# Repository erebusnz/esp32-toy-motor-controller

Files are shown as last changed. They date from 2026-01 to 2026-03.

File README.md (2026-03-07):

# ESP32 Toy Motor Controller

A compact dual DC motor controller board designed around the **ESP32S3-Super Mini** module and the **TB6612FNG** dual H-bridge motor driver.

This project targets small toy hacking with reliable bidirectional DC motor control, PWM speed control, and simple GPIO-controlled switching of accessories.

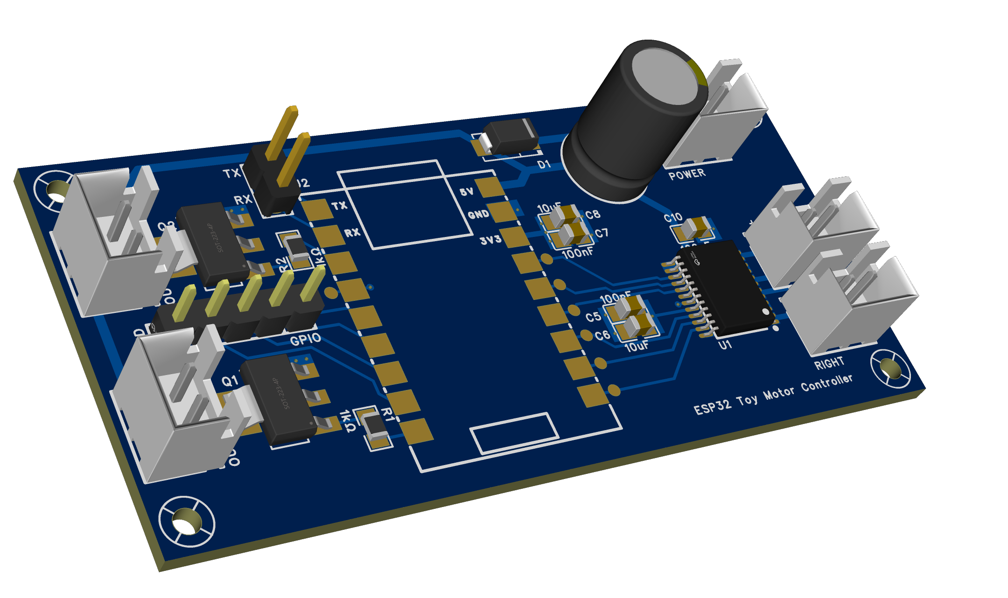
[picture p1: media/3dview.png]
3D PCB Render


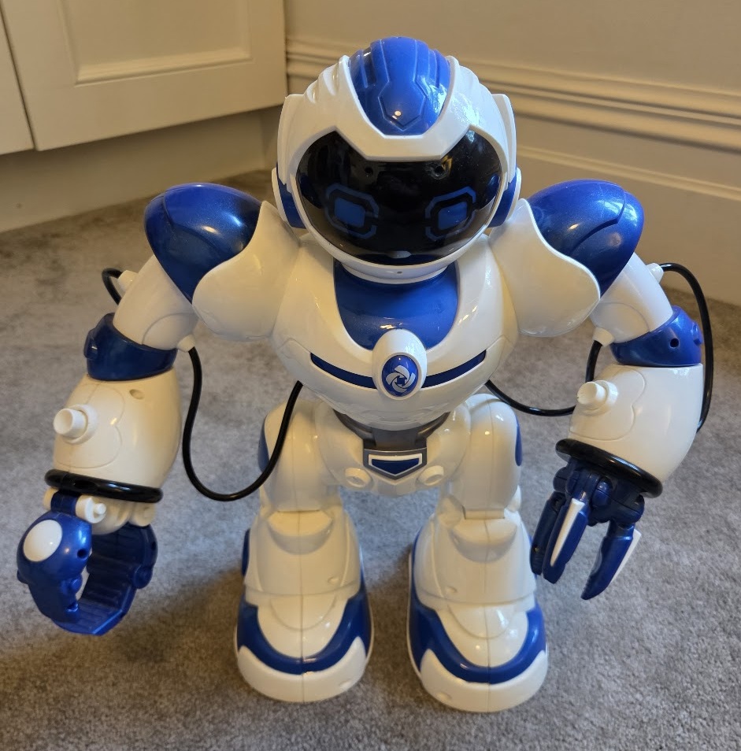
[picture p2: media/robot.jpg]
Robot
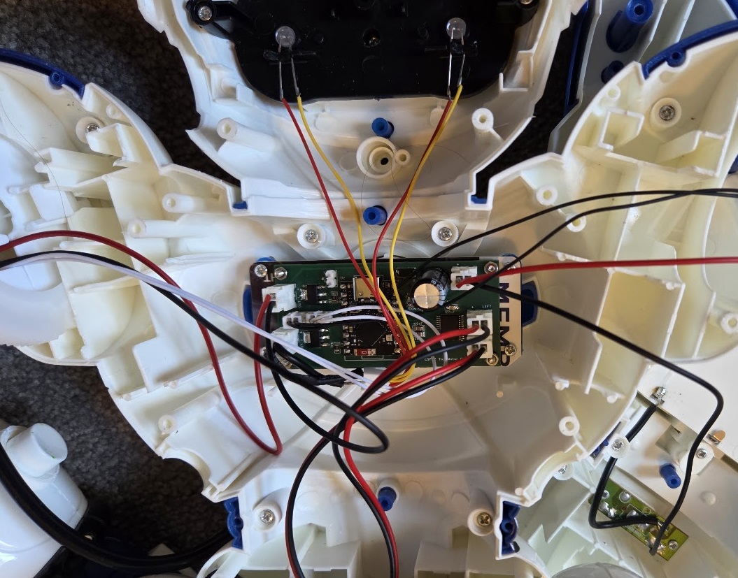
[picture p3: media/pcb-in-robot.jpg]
PCB installed in robot
|  |  |
|:---:|:---:|
| Target toy | PCB installed inside |

---

## Overview

The board integrates:
- An **ESP32S3-Super Mini** module
- A **TB6612FNG** dual H-bridge motor driver
- Two GPIO-controlled low-side switches using NPN transistors
- On-board decoupling and bulk capacitance for motor stability
- Schottky diode reverse polarity protection on the motor supply input
- Serial header and expansion GPIO header

---

## Key Features

- Dual DC motor control (independent speed and direction)
- ESP32-S3 controller with Wi-Fi / BLE capability
- Efficient TB6612FNG motor driver (lower loss than legacy H-bridges)
- Two low-side switched outputs using NPN transistors

---

## Hardware Architecture

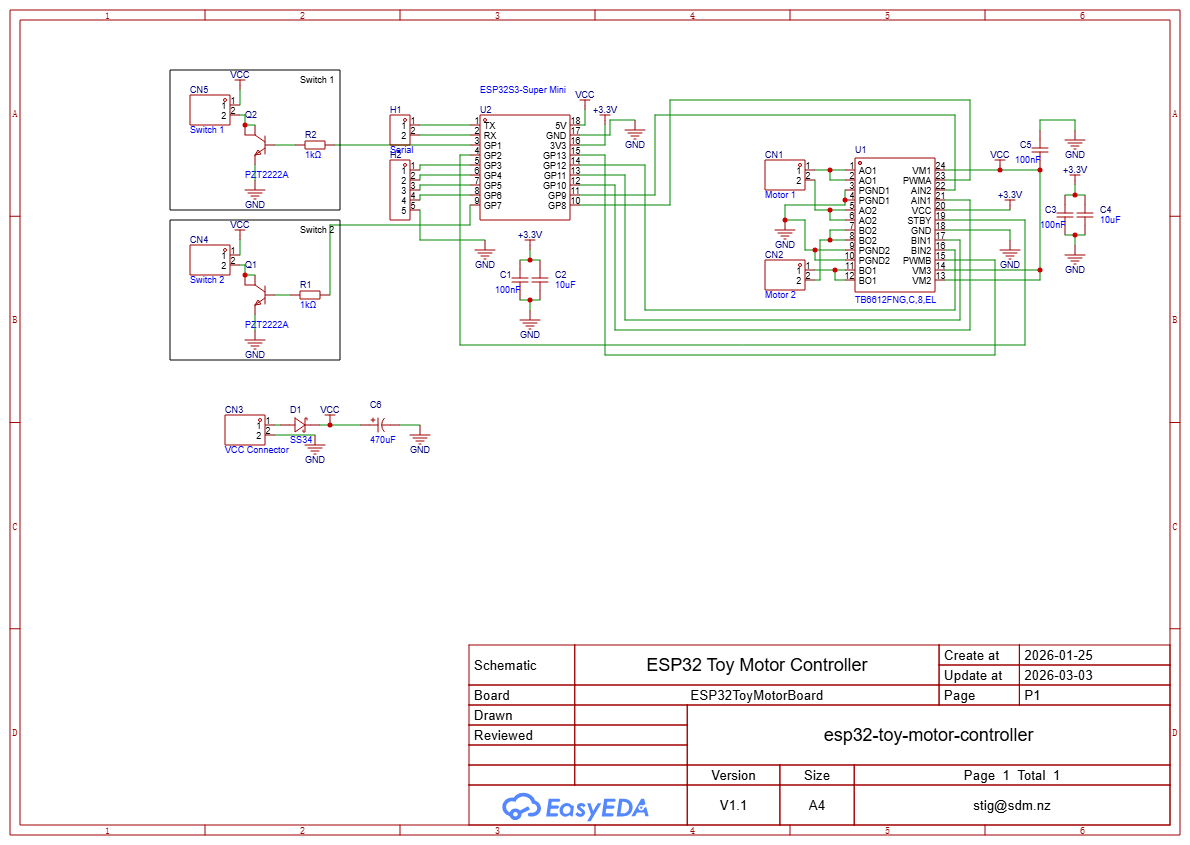
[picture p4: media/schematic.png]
Schematic


### Microcontroller

- **ESP32S3-Super Mini**
- GPIOs directly control motor driver and switch circuitry

### Motor Driver

- **TB6612FNG Dual H-Bridge**
- Motor connections:
  - Motor A: AO1 / AO2
  - Motor B: BO1 / BO2
- Control signals:
  - AIN1, AIN2, PWMA
  - BIN1, BIN2, PWMB
- Motor supply via VM (VCC)

### Power

- **VCC input connector (CN3)**
  - Supplies motor driver VM
  - SS34 Schottky diode (D1) provides reverse polarity protection (~0.4 V forward drop)
  - Bulk capacitor: 470 µF for transient suppression
- **3.3 V logic rail**
  - Local decoupling: 100 nF + 10 µF
- Common ground between logic and motor domains

### Switch Outputs (Low-Side Switching)

- Two GPIO-controlled switches implemented using **NPN transistors**
- Low-side switching topology
- Suitable for driving small loads referenced to VCC

---

## Connectors

| Connector | Function |
|---|---|
| CN1 | Motor 1 output (RIGHT) |
| CN2 | Motor 2 output (LEFT) |
| CN3 | VCC power input |
| CN4 | Switch 2 output |
| CN5 | Switch 1 output |
| H1 | Serial header (TX, RX) |
| H2 | GPIO expansion header (GP3–GP6, GND) |

---

## ESP32S3-Super Mini GPIO Mapping

### Motor Driver (TB6612FNG)

| ESP32S3-Super Mini GPIO | TB6612FNG Signal | Function |
|---|---|---|
| GP2  | STBY | Motor driver enable (HIGH = enabled) |
| GP8  | PWMA | Motor A speed |
| GP10 | AIN1 | Motor A direction |
| GP9  | AIN2 | Motor A direction |
| GP13 | PWMB | Motor B speed |
| GP11 | BIN1 | Motor B direction |
| GP12 | BIN2 | Motor B direction |

### Switch Control

| ESP32S3-Super Mini GPIO | Function |
|---|---|
| GP1 | Switch 1 control |
| GP7 | Switch 2 control |

- Switches use **NPN low-side switching** (PZT2222A): drive GPIO **HIGH to turn the switch ON**, **LOW to turn it OFF**.
- Both switches default to OFF (GPIO LOW) at boot.

### GPIO Expansion (H2)

| H2 Pin | ESP32S3-Super Mini GPIO |
|---|---|
| 1 | GP3 |
| 2 | GP4 |
| 3 | GP5 |
| 4 | GP6 |
| 5 | GND |

---

## Arduino Sketches

### Arduino IDE Setup

- **Board:** ESP32S3 Dev Module
- **Core:** Espressif ESP32 Arduino core v3.x or later — required for `ledcAttach()`. Install via Arduino IDE > Boards Manager > "esp32 by Espressif Systems" >= 3.0.0
- **USB CDC On Boot:** Enabled (for Serial monitor over USB)

All sketches that require WiFi credentials use a `secrets.h` file (not committed). Copy `example.secrets.h` (or `secrets.h.example`) to `secrets.h` and fill in your details:

```cpp
const char *ssid     = "your-network-name";
const char *password = "your-password";
```

---

### `motor-switch-test` — Hardware Test

[`arduino/motor-switch-test/`](arduino/motor-switch-test/)

Confirms motors, switches, and GPIO wiring are working correctly. No WiFi required.

**What it does:**
1. Runs both motors **forward** for 2 s (LED on, SW1 on, SW2 off)
2. Coasts briefly (400 ms)
3. Runs both motors **backward** for 2 s (LED off, SW1 off, SW2 on)
4. Coasts and repeats

**Serial output (115200 baud):**
```
Motor controller ready.
Motor A + B: FORWARD  | SW1 ON, SW2 OFF
Motor A + B: BACKWARD | SW1 OFF, SW2 ON
...
```

---

### `example-ota-controller` — Hardware Test with OTA

[`arduino/example-ota-controller/`](arduino/example-ota-controller/)

Same forward/backward loop as `motor-switch-test`, but adds WiFi connectivity and **ArduinoOTA** support so subsequent firmware updates can be pushed wirelessly.

**After the initial USB flash:**
```bash
python "espota.py" \
  -i <device-ip> \
  -f "build/esp32.esp32.esp32s3/example-ota-controller.ino.bin"
```

The device IP is printed over serial on boot.

Requires `secrets.h` with WiFi credentials (see above).

---

### `wifi-browser-control` — Browser-Based Remote Control

[`arduino/wifi-browser-control/`](arduino/wifi-browser-control/)

Full differential-drive controller served from the ESP32 as a mobile-friendly web page. Includes ArduinoOTA.

Open `http://<device-ip>` in any browser:

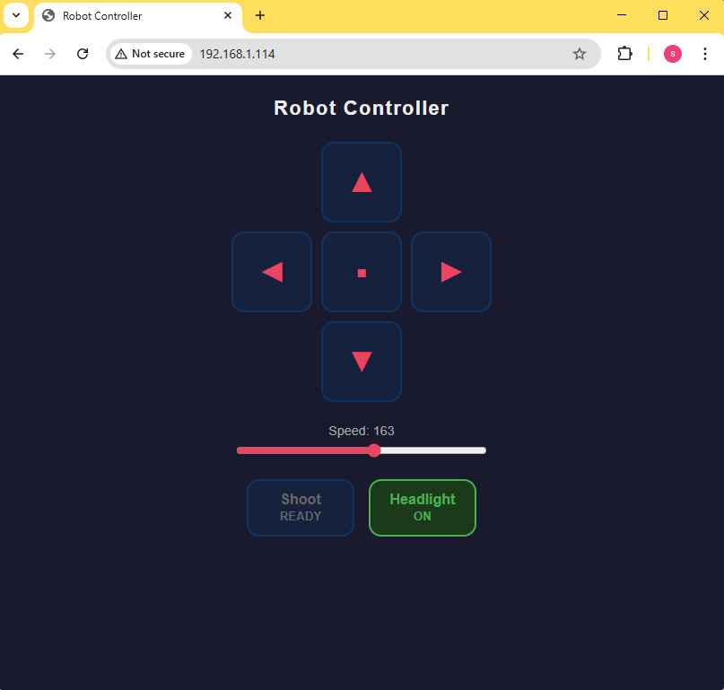
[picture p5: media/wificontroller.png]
Browser controller interface


| Control | Behaviour |
|---|---|
| **↑ Forward** | Both motors forward — hold to move |
| **↓ Backward** | Both motors backward — hold to move |
| **← Left** | Pivot left (right motor fwd, left motor bwd) — hold |
| **→ Right** | Pivot right (left motor fwd, right motor bwd) — hold |
| **■ Stop** | Immediately stops both motors |
| **Speed slider** | Sets motor PWM duty cycle (50–255) |
| **Shoot** | Triggers SW1 for 5 seconds then auto-stops |
| **Headlight** | Toggles SW2 on/off |

Direction buttons stop motors on release. Re-pressing Shoot resets the 5-second timer.

If a motor runs in the wrong direction, flip its flag in the sketch instead of swapping wires:
```cpp
#define REVERSE_RIGHT  true   // CN1 — set true if right motor runs backward
#define REVERSE_LEFT   false  // CN2 — set true if left motor runs backward
```

**OTA upload after initial flash:**
```bash
python "espota.py" \
  -i <device-ip> \
  -f "build/esp32.esp32.esp32s3/wifi-browser-control.ino.bin"
```

Requires `secrets.h` with WiFi credentials (see above).

---

## Power & Electrical Considerations

- Design is intended for **small DC motors and low-current switched loads**
- Motor supply reverse polarity protected by SS34 Schottky diode (~0.4 V drop)
- **Use a dedicated 5 V 1 A+ supply** — USB power causes the 3.3 V rail to sag
- No current sensing
- External motor suppression may be required for noisy loads

---

## Notes & Limitations

- Not suitable for high-current motors
- No hardware fault protection
- ESP32 module pinout must match the 18-pin layout described above

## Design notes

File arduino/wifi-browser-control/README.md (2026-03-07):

# WiFi Browser Control

Browser-based controller for the ESP32S3 toy motor controller PCB.
Drives two DC motors (differential drive) and controls a shoot actuator and headlight via a mobile-friendly webpage.

## Hardware

- **MCU:** ESP32S3-Super Mini
- **Motor driver:** TB6612FNG dual H-bridge
- **Supply:** 5 V, 1 A minimum (USB power causes 3.3 V rail sag — use a dedicated supply)

## PCB Connectors

| Connector | Silkscreen label | Function | GPIO | Notes |
|---|---|---|---|---|
| **CN1** | Right | Right motor | — | |
| **CN2** | Left | Left motor | — | |
| **CN4** | Out 2 | Headlight | GP7  | Requires current-limiting resistor — 68 Ω for LED |
| **CN5** | Out 1 | Shoot actuator | GP1  | |

> If a motor runs in the wrong direction, flip its flag in the sketch instead of swapping wires:
> ```cpp
> #define REVERSE_RIGHT  true   // CN1 — set true if right motor runs backward
> #define REVERSE_LEFT   false  // CN2 — set true if left motor runs backward
> ```

## GPIO Map

| GPIO | Function |
|---|---|
| 2 | STBY (motor enable) |
| 8 | PWMA (right motor speed) |
| 9 | AIN2 |
| 10 | AIN1 |
| 11 | BIN1 |
| 12 | BIN2 |
| 13 | PWMB (left motor speed) |
| 1 | SW1 — Shoot actuator (CN5) |
| 7 | SW2 — Headlight (CN4) |
| 48 | Onboard LED |

## Arduino IDE Setup

| Setting | Value |
|---|---|
| Board | ESP32S3 Dev Module |
| Core | Espressif ESP32 v3.x or later |
| USB CDC On Boot  | Enabled |
| Upload speed | 921600 |

WiFi credentials go in `secrets.h` (not committed). Rename `example.secrets.h` to `secrets.h` and fill in your details:

```cpp
const char *ssid     = "your-network-name";
const char *password = "your-password";
```

## OTA Upload
After the initial USB flash, subsequent uploads can remote upload firmware over wifi using `espota.py`:

In Arduino 2 use Sketch -> Export Compiled Binary then:

```bash
python "espota.py" \
  -i <device-ip> \
  -f "build/esp32.esp32.esp32s3/wifi-browser-control.ino.bin"
```

The device IP is printed over serial on boot.

## Web Interface

Open `http://<device-ip>` in any browser (works on mobile).

Browser controller interface

| Control | Behaviour |
|---|---|
| **↑ Forward** | Both motors forward — hold to move |
| **↓ Backward**  | Both motors backward — hold to move |
| **← Left** | Pivot left (right motor fwd, left motor bwd) — hold |
| **→ Right** | Pivot right (left motor fwd, right motor bwd) — hold |
| **■ Stop** | Immediately stops both motors |
| **Speed slider**| Sets motor PWM duty cycle (50–255) |
| **Shoot** | Triggers SW1 actuator for 5 seconds then auto-stops |
| **Headlight** | Toggles SW2 on/off |

Direction buttons stop the motors on release. The Shoot button re-pressing resets the 5-second timer.

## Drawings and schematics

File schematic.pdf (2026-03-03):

# GP8 10 GP9 11 GP10 12 GP11 13 GP12 14 GP13 15 3V3 16 GND 17 5V 18

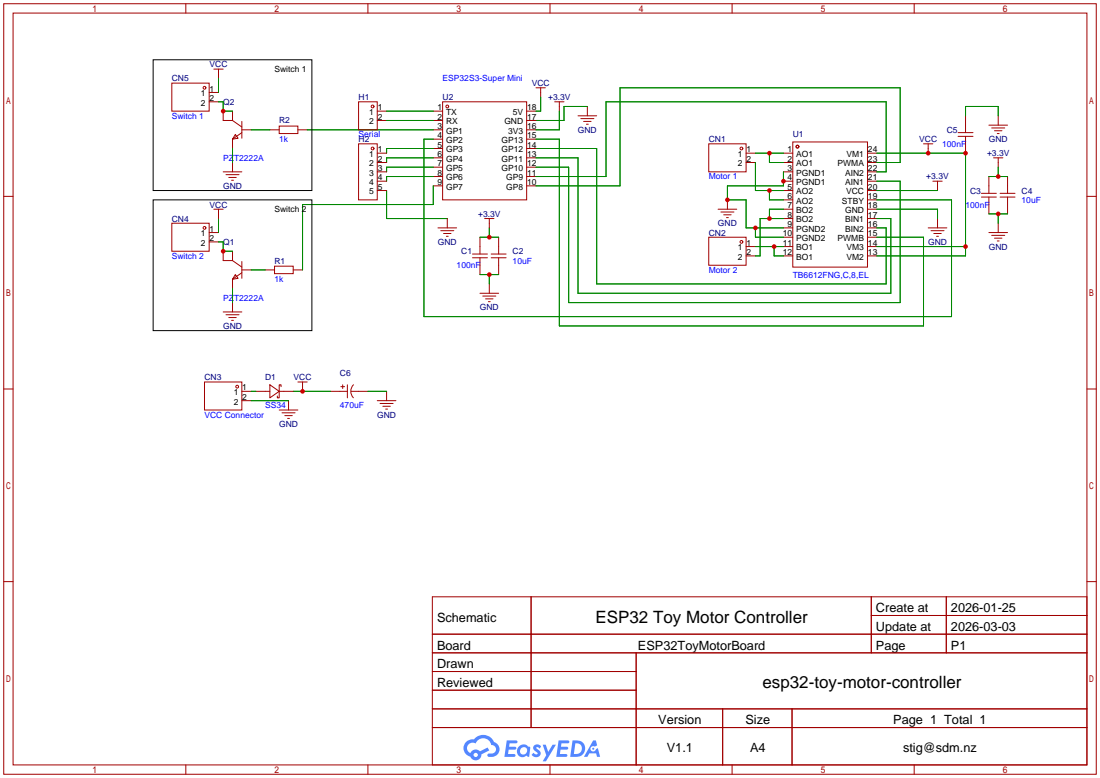
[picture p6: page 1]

Schematic | ESP32 Toy Motor Controller | Create at | 2026-01-25

Update at | 2026-03-03

Board | ESP32ToyMotorBoard | Page | P1
Drawn | | esp32-toy-motor-controller
Reviewed

Version | Size | Page 1 Total 1
V1.1 | A4 | stig@sdm.nz

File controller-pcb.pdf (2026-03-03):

# ESP32 Toy Motor Controller +

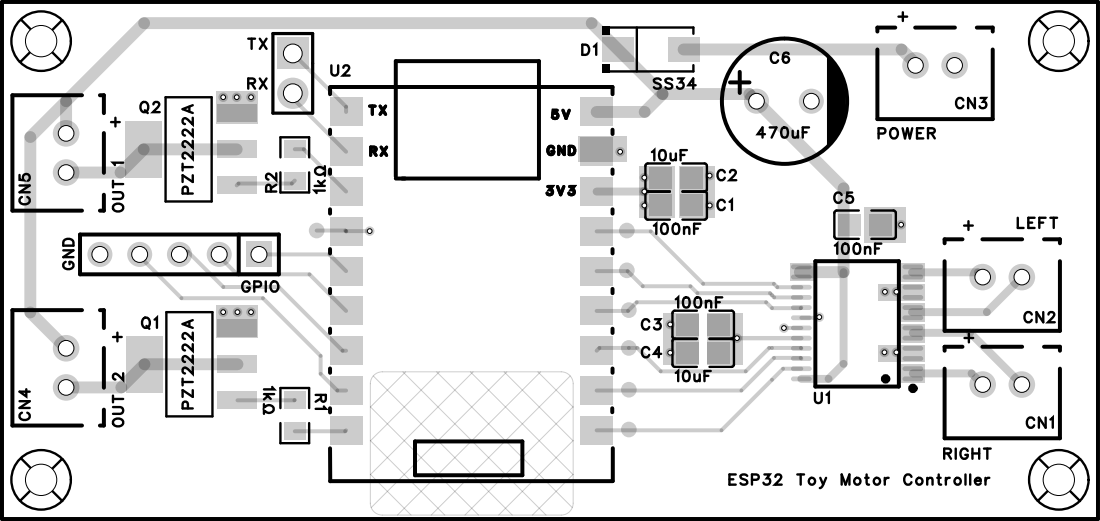
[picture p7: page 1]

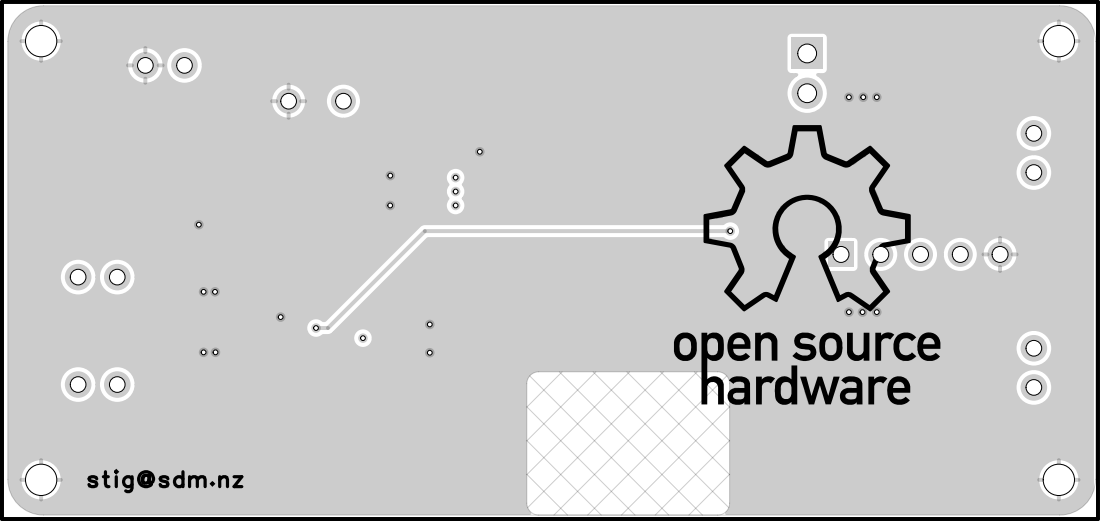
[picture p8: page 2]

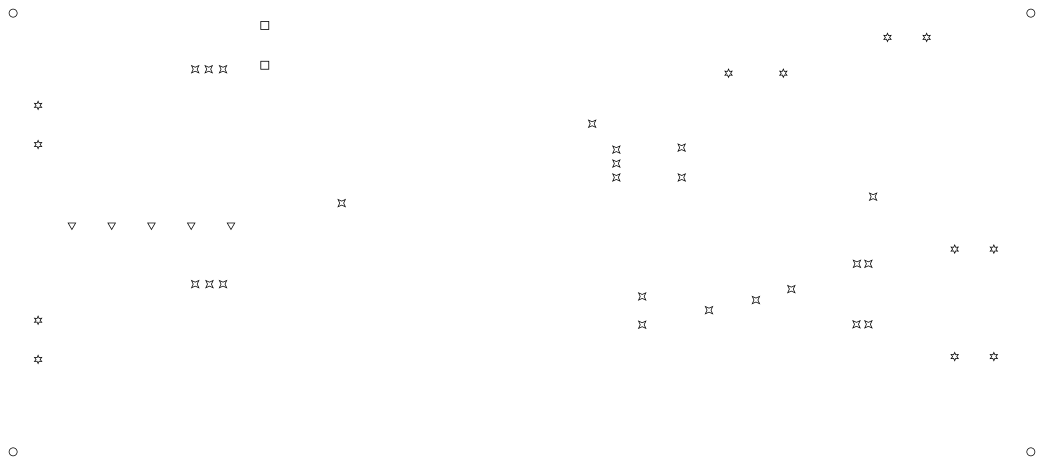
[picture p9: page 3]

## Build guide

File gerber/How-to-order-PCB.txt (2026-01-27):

How to Order PCB

Please refer to:
https://prodocs.easyeda.com/en/pcb/order-order-pcb/index.html

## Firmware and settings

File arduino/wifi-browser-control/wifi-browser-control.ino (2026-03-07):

// ESP32 Toy Motor Controller - WiFi Browser Control with OTA
// Hardware: ESP32S3-Super Mini + TB6612FNG dual H-bridge motor driver
//
// IMPORTANT - Arduino IDE setup:
//   Board:     ESP32S3 Dev Module
//   Core:      Espressif ESP32 Arduino core v3.x or later (required for ledcAttach)
//   Upload speed: 921600, USB CDC On Boot: Enabled

#include <WiFi.h>
#include "esp_wifi.h"
#include <ESPmDNS.h>
#include <NetworkUdp.h>
#include <ArduinoOTA.h>
#include <WebServer.h>
#include "secrets.h"

uint32_t last_ota_time = 0;

// --- Motor A Pins (TB6612FNG) - Left motor ---
#define PWMA  8
#define AIN1  10
#define AIN2  9

// --- Motor B Pins (TB6612FNG) - Right motor ---
#define PWMB  13
#define BIN1  11
#define BIN2  12

// --- TB6612FNG Standby (HIGH = enabled, LOW = standby) ---
#define STBY  2

// --- Switch Outputs (NPN low-side: HIGH = ON, LOW = OFF) ---
#define SW1   1
#define SW2   7

// --- Onboard LED ---
#define LED   48

// --- Motor direction flags ---
// Set to true if a motor runs backward — avoids swapping physical wires
#define REVERSE_RIGHT  true   // CN1 Right motor
#define REVERSE_LEFT   false  // CN2 Left motor

// --- PWM Settings ---
#define PWM_FREQ        5000
#define PWM_RESOLUTION  8     // 0-255

// TB6612FNG direction truth table:
//   AIN1=H, AIN2=L -> Forward
//   AIN1=L, AIN2=H -> Backward
//   AIN1=L, AIN2=L -> Coast (stop)

bool sw1_state = false;
bool sw2_state = false;
uint32_t sw1_off_at = 0;  // millis() timestamp to auto-off SW1 (0 = not scheduled)

WebServer server(80);

// ----- Motor helpers -----

void motorA_forward(uint8_t speed) {
  digitalWrite(AIN1, REVERSE_RIGHT ? LOW  : HIGH);
  digitalWrite(AIN2, REVERSE_RIGHT ? HIGH : LOW);
  ledcWrite(PWMA, speed);
}
void motorA_backward(uint8_t speed) {
  digitalWrite(AIN1, REVERSE_RIGHT ? HIGH : LOW);
  digitalWrite(AIN2, REVERSE_RIGHT ? LOW  : HIGH);
  ledcWrite(PWMA, speed);
}
void motorA_stop() {
  digitalWrite(AIN1, LOW); digitalWrite(AIN2, LOW);
  ledcWrite(PWMA, 0);
}

void motorB_forward(uint8_t speed) {
  digitalWrite(BIN1, REVERSE_LEFT ? LOW  : HIGH);
  digitalWrite(BIN2, REVERSE_LEFT ? HIGH : LOW);
  ledcWrite(PWMB, speed);
}
void motorB_backward(uint8_t speed) {
  digitalWrite(BIN1, REVERSE_LEFT ? HIGH : LOW);
  digitalWrite(BIN2, REVERSE_LEFT ? LOW  : HIGH);
  ledcWrite(PWMB, speed);
}
void motorB_stop() {
  digitalWrite(BIN1, LOW); digitalWrite(BIN2, LOW);
  ledcWrite(PWMB, 0);
}

// ----- Web page -----

static const char INDEX_HTML[] PROGMEM = R"rawliteral(
<!DOCTYPE html>
<html lang="en">
<head>
<meta charset="UTF-8">
<meta name="viewport" content="width=device-width, initial-scale=1.0, user-scalable=no">
<title>Robot Controller</title>
<style>
  * { box-sizing: border-box; margin: 0; padding: 0; }
  body {
    background: #1a1a2e; color: #eee; font-family: sans-serif;
    display: flex; flex-direction: column; align-items: center;
    min-height: 100vh; padding: 24px 16px; gap: 24px;
  }
  h1 { font-size: 1.4em; letter-spacing: 0.05em; }
  .dpad {
    display: grid;
    grid-template-columns: repeat(3, 90px);
    grid-template-rows: repeat(3, 90px);
    gap: 10px;
  }
  .btn {
    background: #16213e; border: 2px solid #0f3460;
    border-radius: 14px; color: #e94560; font-size: 2em;
    cursor: pointer; user-select: none; touch-action: none;
    display: flex; align-items: center; justify-content: center;
    -webkit-tap-highlight-color: transparent;
    transition: background 0.08s, border-color 0.08s;
  }
  .btn:active, .btn.pressed { background: #0f3460; border-color: #e94560; }
  .empty { visibility: hidden; }
  .speed-row {
    display: flex; flex-direction: column; align-items: center; gap: 6px;
    width: 280px;
  }
  .speed-row label { font-size: 0.9em; color: #aaa; }
  input[type=range] { width: 100%; accent-color: #e94560; }
  .switches { display: flex; gap: 16px; }
  .sw-btn {
    width: 120px; height: 64px; border-radius: 14px;
    font-size: 1em; font-weight: bold;
    border: 2px solid #0f3460; background: #16213e; color: #666;
    cursor: pointer; touch-action: manipulation;
    -webkit-tap-highlight-color: transparent;
    transition: background 0.1s, border-color 0.1s, color 0.1s;
  }
  .sw-btn.on  { background: #1a3a1a; border-color: #4caf50; color: #4caf50; }
  .sw-btn.firing { background: #3a1a1a; border-color: #e94560; color: #e94560; }
  #status { font-size: 0.8em; color: #555; min-height: 1.2em; }
</style>
</head>
<body>
<h1>Robot Controller</h1>

<div class="dpad">
  <div class="empty"></div>
  <button class="btn" id="fwd">&#x25B2;</button>
  <div class="empty"></div>

  <button class="btn" id="left">&#x25C4;</button>
  <button class="btn" id="stop_btn" style="font-size:1.2em;">&#x25A0;</button>
  <button class="btn" id="right">&#x25BA;</button>

  <div class="empty"></div>
  <button class="btn" id="back">&#x25BC;</button>
  <div class="empty"></div>
</div>

<div class="speed-row">
  <label>Speed: <span id="spd_lbl">180</span></label>
  <input type="range" id="speed" min="50" max="255" value="180"
    oninput="document.getElementById('spd_lbl').textContent=this.value">
</div>

<div class="switches">
  <button class="sw-btn" id="sw1_btn" onclick="cmd('sw1')">Shoot<br><small>READY</small></button>
  <button class="sw-btn" id="sw2_btn" onclick="cmd('sw2')">Headlight<br><small>OFF</small></button>
</div>

<div id="status"></div>

<script>
function speed() { return document.getElementById('speed').value; }

function cmd(action) {
  fetch('/cmd?action=' + action + '&speed=' + speed())
    .then(r => r.json())
    .then(s => {
      const sw1 = document.getElementById('sw1_btn');
      const sw2 = document.getElementById('sw2_btn');
      sw1.className = 'sw-btn' + (s.sw1 ? ' firing' : '');
      sw1.innerHTML = 'Shoot<br><small>' + (s.sw1 ? 'FIRING' : 'READY') + '</small>';
      sw2.className = 'sw-btn' + (s.sw2 ? ' on' : '');
      sw2.innerHTML = 'Headlight<br><small>' + (s.sw2 ? 'ON' : 'OFF') + '</small>';
    })
    .catch(() => { document.getElementById('status').textContent = 'Connection lost'; });
}

// Hold-to-move buttons: pointerdown = move, pointerup/leave = stop
const moveMap = { fwd: 'forward', left: 'left', right: 'right', back: 'backward' };
Object.entries(moveMap).forEach(([id, action]) => {
  const el = document.getElementById(id);
  el.addEventListener('pointerdown', e => { e.preventDefault(); el.classList.add('pressed'); cmd(action); });
  el.addEventListener('pointerup',   e => { el.classList.remove('pressed'); cmd('stop'); });
  el.addEventListener('pointerleave',e => { el.classList.remove('pressed'); cmd('stop'); });
});

document.getElementById('stop_btn').addEventListener('click', () => cmd('stop'));
</script>
</body>
</html>
)rawliteral";

// ----- HTTP handlers -----

void handleRoot() {
  server.send_P(200, "text/html", INDEX_HTML);
}

void handleCmd() {
  if (!server.hasArg("action")) {
    server.send(400, "text/plain", "Missing action");
    return;
  }

  String action = server.arg("action");
  uint8_t spd = 180;
  if (server.hasArg("speed")) {
    spd = (uint8_t)constrain(server.arg("speed").toInt(), 0, 255);
  }

  if      (action == "forward")  { motorA_forward(spd);  motorB_forward(spd);  }
  else if (action == "backward") { motorA_backward(spd); motorB_backward(spd); }
  else if (action == "left")     { motorA_forward(spd);  motorB_backward(spd); }  // pivot left
  else if (action == "right")    { motorA_backward(spd); motorB_forward(spd);  }  // pivot right
  else if (action == "stop")     { motorA_stop(); motorB_stop(); }
  else if (action == "sw1")      { sw1_state = true; digitalWrite(SW1, HIGH); sw1_off_at = millis() + 5000; }
  else if (action == "sw2")      { sw2_state = !sw2_state; digitalWrite(SW2, sw2_state); }

  String json = "{\"sw1\":" + String(sw1_state ? "true" : "false") +
                ",\"sw2\":" + String(sw2_state ? "true" : "false") + "}";
  server.send(200, "application/json", json);
}

// ----- Setup -----

void setup() {
  Serial.begin(115200);
  Serial.println("Booting");

  WiFi.mode(WIFI_STA);
  esp_wifi_set_max_tx_power(34);  // 8.5 dBm — needed for Super Mini on UniFi
  WiFi.begin(ssid, password);
  while (WiFi.waitForConnectResult() != WL_CONNECTED) {
    Serial.println("Connection failed, rebooting...");
    delay(5000);
    ESP.restart();
  }

  ArduinoOTA
    .onStart([]() {
      motorA_stop(); motorB_stop();  // safe state before flashing
      String type = (ArduinoOTA.getCommand() == U_FLASH) ? "sketch" : "filesystem";
      Serial.println("OTA start: " + type);
    })
    .onEnd([]()   { Serial.println("\nOTA end"); })
    .onProgress([](unsigned int progress, unsigned int total) {
      if (millis() - last_ota_time > 500) {
        Serial.printf("OTA: %u%%\n", progress / (total / 100));
        last_ota_time = millis();
      }
    })
    .onError([](ota_error_t error) {
      const char* msg = "Unknown";
      if      (error == OTA_AUTH_ERROR)    msg = "Auth failed";
      else if (error == OTA_BEGIN_ERROR)   msg = "Begin failed";
      else if (error == OTA_CONNECT_ERROR) msg = "Connect failed";
      else if (error == OTA_RECEIVE_ERROR) msg = "Receive failed";
      else if (error == OTA_END_ERROR)     msg = "End failed";
      Serial.printf("OTA error[%u]: %s\n", error, msg);
    });

  ArduinoOTA.begin();

  server.on("/",    handleRoot);
  server.on("/cmd", handleCmd);
  server.begin();

  Serial.print("Ready — http://");
  Serial.println(WiFi.localIP());

  // --- GPIO setup ---
  pinMode(STBY, OUTPUT); digitalWrite(STBY, HIGH);
  pinMode(LED,  OUTPUT);
  pinMode(AIN1, OUTPUT); pinMode(AIN2, OUTPUT);
  pinMode(BIN1, OUTPUT); pinMode(BIN2, OUTPUT);
  pinMode(SW1,  OUTPUT); digitalWrite(SW1, LOW);
  pinMode(SW2,  OUTPUT); digitalWrite(SW2, LOW);

  ledcAttach(PWMA, PWM_FREQ, PWM_RESOLUTION);
  ledcAttach(PWMB, PWM_FREQ, PWM_RESOLUTION);

  motorA_stop();
  motorB_stop();

  Serial.println("Motor controller ready.");
}

// ----- Loop -----

void loop() {
  ArduinoOTA.handle();
  server.handleClient();

  // Auto-off SW1 (Shoot) after 5s
  if (sw1_off_at && millis() >= sw1_off_at) {
    sw1_state = false;
    digitalWrite(SW1, LOW);
    sw1_off_at = 0;
  }
}

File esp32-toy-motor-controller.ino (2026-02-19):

// ESP32 Toy Motor Controller - Motor A & B Forward/Backward Toggle Example
// Hardware: ESP32S3-Super Mini + TB6612FNG dual H-bridge motor driver
//
// IMPORTANT - Arduino IDE setup:
//   Board:     ESP32S3 Dev Module
//   Core:      Espressif ESP32 Arduino core v3.x or later (required for ledcAttach)
//   Upload speed: 921600, USB CDC On Boot: Enabled

// --- Motor A Pins (TB6612FNG) ---
#define PWMA  8   // Motor A PWM speed
#define AIN1  10  // Motor A direction control 1
#define AIN2  9   // Motor A direction control 2

// --- Motor B Pins (TB6612FNG) ---
#define PWMB  13  // Motor B PWM speed
#define BIN1  11  // Motor B direction control 1
#define BIN2  12  // Motor B direction control 2

// --- TB6612FNG Standby (HIGH = motor driver enabled, LOW = standby/disabled) ---
#define STBY  2

// --- Switch Outputs (NPN low-side: GPIO HIGH = switch ON, GPIO LOW = switch OFF) ---
#define SW1   1
#define SW2   7

// --- Onboard LED ---
#define LED   48

// --- PWM Settings ---
#define PWM_FREQ        5000  // Hz
#define PWM_RESOLUTION  8     // bits (duty cycle range: 0-255)
#define MOTOR_SPEED     180   // 0-255

// TB6612FNG direction truth table:
//   AIN1=H, AIN2=L -> Forward
//   AIN1=L, AIN2=H -> Backward
//   AIN1=L, AIN2=L -> Coast (stop)
//   AIN1=H, AIN2=H -> Brake
//
// STBY pin is hardwired HIGH on the PCB — motor driver is always enabled.

// --- DIAGNOSTIC MODE ---
// Set to true to bypass LEDC and drive PWMA/PWMB fully HIGH with digitalWrite.
// If motors run in diagnostic mode but not normal mode, the fault is in ledcAttach/ledcWrite.
// If motors do not run in diagnostic mode either, the fault is hardware (check VM power at CN3).
#define DIAGNOSTIC_MODE false

void motorA_forward(uint8_t speed) {
  digitalWrite(AIN1, HIGH);
  digitalWrite(AIN2, LOW);
  if (DIAGNOSTIC_MODE) digitalWrite(PWMA, HIGH);
  else                  ledcWrite(PWMA, speed);
}

void motorA_backward(uint8_t speed) {
  digitalWrite(AIN1, LOW);
  digitalWrite(AIN2, HIGH);
  if (DIAGNOSTIC_MODE) digitalWrite(PWMA, HIGH);
  else                  ledcWrite(PWMA, speed);
}

void motorA_stop() {
  digitalWrite(AIN1, LOW);
  digitalWrite(AIN2, LOW);
  if (DIAGNOSTIC_MODE) digitalWrite(PWMA, LOW);
  else                  ledcWrite(PWMA, 0);
}

void motorB_forward(uint8_t speed) {
  digitalWrite(BIN1, HIGH);
  digitalWrite(BIN2, LOW);
  if (DIAGNOSTIC_MODE) digitalWrite(PWMB, HIGH);
  else                  ledcWrite(PWMB, speed);
}

void motorB_backward(uint8_t speed) {
  digitalWrite(BIN1, LOW);
  digitalWrite(BIN2, HIGH);
  if (DIAGNOSTIC_MODE) digitalWrite(PWMB, HIGH);
  else                  ledcWrite(PWMB, speed);
}

void motorB_stop() {
  digitalWrite(BIN1, LOW);
  digitalWrite(BIN2, LOW);
  if (DIAGNOSTIC_MODE) digitalWrite(PWMB, LOW);
  else                  ledcWrite(PWMB, 0);
}

void setup() {
  Serial.begin(115200);

  pinMode(STBY, OUTPUT);
  digitalWrite(STBY, HIGH);  // enable motor driver immediately

  pinMode(LED,  OUTPUT);
  pinMode(AIN1, OUTPUT);
  pinMode(AIN2, OUTPUT);
  pinMode(BIN1, OUTPUT);
  pinMode(BIN2, OUTPUT);
  pinMode(PWMA, OUTPUT);
  pinMode(PWMB, OUTPUT);
  pinMode(SW1,  OUTPUT);
  pinMode(SW2,  OUTPUT);

  // Switches default OFF (NPN: GPIO LOW = transistor off = switch OFF)
  digitalWrite(SW1, LOW);
  digitalWrite(SW2, LOW);

  if (!DIAGNOSTIC_MODE) {
    // Attach PWM to motor speed pins — requires ESP32 Arduino core v3+
    ledcAttach(PWMA, PWM_FREQ, PWM_RESOLUTION);
    ledcAttach(PWMB, PWM_FREQ, PWM_RESOLUTION);
  }

  motorA_stop();
  motorB_stop();

  Serial.println(DIAGNOSTIC_MODE
    ? "DIAGNOSTIC MODE: PWMA/PWMB driven HIGH via digitalWrite (no PWM)"
    : "Normal mode: PWM via ledcAttach");
  Serial.println("Motor controller ready.");
}

void loop() {
  // --- Forward ---
  Serial.println("Motor A + B: FORWARD  | SW1 ON, SW2 OFF");
  digitalWrite(LED, HIGH);
  digitalWrite(SW1, HIGH);   // SW1 ON
  digitalWrite(SW2, LOW);    // SW2 OFF
  motorA_forward(MOTOR_SPEED);
  motorB_forward(MOTOR_SPEED);
  delay(2000);

  // --- Brief stop between directions ---
  motorA_stop();
  motorB_stop();
  digitalWrite(SW1, LOW);    // both switches OFF during stop
  digitalWrite(SW2, LOW);
  delay(400);

  // --- Backward ---
  Serial.println("Motor A + B: BACKWARD | SW1 OFF, SW2 ON");
  digitalWrite(LED, LOW);
  digitalWrite(SW1, LOW);    // SW1 OFF
  digitalWrite(SW2, HIGH);   // SW2 ON
  motorA_backward(MOTOR_SPEED);
  motorB_backward(MOTOR_SPEED);
  delay(2000);

  // --- Brief stop before repeating ---
  motorA_stop();
  motorB_stop();
  digitalWrite(SW1, LOW);    // both switches OFF during stop
  digitalWrite(SW2, LOW);
  delay(400);
}

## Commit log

2026-01-27 Added
    Added project from EasyEDA
    [Drill_PTH_Through.DRL, Drill_PTH_Through_Via.DRL, Gerber_BoardOutlineLayer.GKO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]
2026-02-19 Add motor control sketch and fix PCB v1.1 STBY routing bug
    - Add esp32-toy-motor-controller.ino: forward/backward toggle for Motor A and B
    with PWM speed control, switch outputs, diagnostic mode, and STBY enable via GP2
    - Fix critical PCB bug: STBY (TB6612FNG pin 19) was routed to GND, now routed to GP2 (GPIO2)
    - Correct MCU identification from ESP32C3 to ESP32S3-Super Mini throughout
    - Fix switch logic: NPN transistors require HIGH=ON, LOW=OFF (was documented backwards)
    - Update README: correct GPIO mapping including STBY, Arduino IDE setup requirements,
    full software section with example code and TB6612FNG truth table
    - PCB v1.1: add polarity markers on CN3, CN4, CN5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
    [esp32-toy-motor-controller.ino]
2026-02-20 Updated PCB and schematic to v1.1
    Added reverse polarity protection, polarity signs for connectors, added test pins for H bridge, added pin-headers for spare IO connection
2026-02-20 Updated PCB to v1.1
    [Drill_PTH_Through.DRL, Drill_PTH_Through_Via.DRL, Gerber_BoardOutlineLayer.GKO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]
2026-02-21 Update README.md
    Updated README.md with revised v1.1 schematic
2026-02-21 Added decoupling cap to U1 for VCC
    Updated schematic to include decoupling capacitor
    [Drill_PTH_Through.DRL, Drill_PTH_Through_Via.DRL, Gerber_BoardOutlineLayer.GKO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]
2026-02-21 Revised motor gnd vias
    [Drill_PTH_Through.DRL, Drill_PTH_Through_Via.DRL, Gerber_BoardOutlineLayer.GKO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]
2026-03-03 D1 polarity fixed
    [Drill_PTH_Through.DRL, Drill_PTH_Through_Via.DRL, Gerber_BoardOutlineLayer.GKO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]
2026-03-03 Added BOM and fixed capacity numbering
2026-03-03 Fixed capacity ordering
    [Drill_PTH_Through.DRL, Drill_PTH_Through_Via.DRL, Gerber_BoardOutlineLayer.GKO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]
